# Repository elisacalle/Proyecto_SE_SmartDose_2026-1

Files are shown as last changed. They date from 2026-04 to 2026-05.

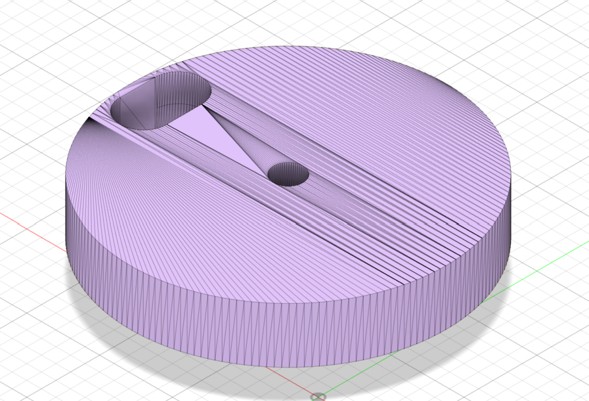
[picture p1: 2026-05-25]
Imágenes/Rotador.jpg

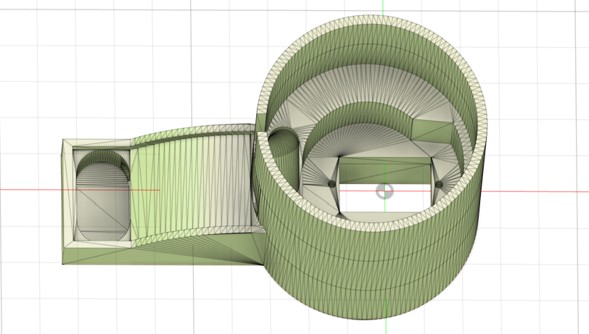
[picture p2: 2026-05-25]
Imágenes/base_sistema.jpg

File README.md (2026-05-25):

# SmartDose: Sistema Automatizado de Dispensación de Medicamentos Programados

## Introducción
#### Contexto del problema:
A medida que la población colombiana tiende al envejecimiento, y el aumento sostenido de enfermedades crónicas, tales como diabetes o hipertensión, ha generado un escenario en el que millones de personas dependen de instrucciones farmacológicas complejas y específicas para conservar su calidad de vida. Sin embargo, gestionar mentalmente qué se debe tomar y a qué hora, representa una carga cognitiva considerable, principalmente entre los adultos mayores que no tienen un cuidador constante. Dicho esto, el olvido de tomar los medicamentos no es un evento irrelevante, puede desencadenar crisis de salud, empeoramiento del cuadro clínico que deriva en hospitalizaciones de emergencia o el deterioro acelerado de las condiciones a tratar, todas consecuencias que, con la administración correcta de los fármacos, se pueden controlar.

#### Importancia y por qué vale la pena resolverlo:
La mala adherencia terapéutica no resulta en consecuencias únicamente para el paciente: representa una sobrecarga al ya presionado sistema de salud pública y a las familias que deben asumir el esfuerzo económico y de tiempo para acompañar a su ser querido y garantizar su bienestar. Si se logra automatizar la dispensación de medicamentos, se elimina el eslabón más débil de la cadena, la memoria humana y la capacidad de seguir indicaciones; más allá del beneficio directo que obtiene el paciente al seguir con su tratamiento como está estipulado, esta solución también les devuelve libertad a los pacientes y reduce la carga del entorno familiar. Resolver este problema con un sistema embebido de bajo costo convierte la solución en una replicable, accesible y sobre todo útil para la sociedad.

#### Área de aplicación:
SmartDose se encuentra justo en la frontera donde, los sistemas embebidos, la ingeniería aplicada a la salud y automatización y control se encuentran. No es un dispositivo médico en el sentido legal o regulatorio, es una solución de ingeniería orientada a un problema humano concreto, dándole visibilidad a las dificultades que día a día pueden enfrentar los enfermos crónicos para su tratamiento. Este proyecto aspira a demostrar como la electrónica, sensores de bajo costo y microcontroladores tienen la capacidad de construir herramientas que impacten realmente a la sociedad.

## Descripción del Problema

La adherencia terapéutica, entendida como el cumplimiento correcto de un tratamiento farmacológico en dosis, frecuencia y horario, representa uno de los desafíos más críticos en el cuidado de pacientes con enfermedades crónicas. Según la Organización Mundial de la Salud, cerca del 50% de los pacientes con enfermedades crónicas no toman sus medicamentos de la forma prescrita, lo que deriva en complicaciones clínicas evitables, hospitalizaciones innecesarias y un deterioro progresivo de la calidad de vida. Este problema se agudiza significativamente en adultos mayores, quienes con frecuencia deben gestionar múltiples medicamentos con horarios distintos, presentan dificultades cognitivas asociadas al envejecimiento y en muchos casos no cuentan con acompañamiento permanente de un cuidador.

La situación actual en hogares y entornos de cuidado domiciliario depende casi exclusivamente de la memoria del paciente o de recordatorios manuales por parte de los familiares o cuidadores. Los pastilleros convencionales, aunque organizan visualmente la medicación por días y tomas, no generan alertas, no verifican si la pastilla fue tomada efectivamente y no registran el historial de dispensaciones. Las alarmas de celular, si bien son una solución parcial, requieren que el paciente identifique correctamente cuál medicamento tomar, en qué dosis y en qué momento, lo que en pacientes con deterioro cognitivo representa una fuente frecuente de errores. 

Se identifica que lo que falta es un sistema autónomo, embebido y de bajo costo que gestione de forma automática los horarios de medicación, dispense físicamente el medicamento en el momento correcto, alerte al paciente de forma sonora para que no ignore la toma, detecte si el compartimiento está vacío antes de intentar dispensar y registre con trazabilidad temporal cada evento relevante del proceso. Un sistema así eliminaría la dependencia de la memoria del paciente, reduciría los errores de medicación y proporcionaría al cuidador o familiar un historial consultable del comportamiento del sistema.

Un caso aplicado puede ser el de la abuela de uno de nuestros integrantes, que debido a la diabetes y su avanzada edad debe tomar durante el día diferentes cantidades de medicamentos a horas muy exactas. Debido a su condición de vejez es propensa a que se le olvide tomarlos a las horas precisas y adecuadas, como aún vive sola, para su familia tiende a ser un poco complejo supervisar o consultar todo el historial de toma de las pastillas de forma adecuada, la invención de este sistema sería una alternativa o solución bastante factible para su condición y de esta forma podría sentirse mas independiente y a su familia le daría la tranquilidad de que cumple de forma precisa con la toma de sus medicamentos. 

## Alcance del Proyecto
#### ¿Qué incluye el proyecto?
-Programación de hasta 4 horarios de dispensación diarios configurables desde la GUI (Graphical User Interface).

-Dispensación automática de n dosis (pastilla) por evento programado.

-Detección de si la pastilla fue dispensada correctamente mediante sensor de presencia.

-Alerta sonora y visual (buzzer + led) si el usuario no recoge la pastilla después de un tiempo.

-Sistema de logging con timestamp, niveles INFO/WARN/ERROR y códigos estructurados. Se utiliza comunicación UART.

-Interfaz gráfica NX4832K035, pantalla táctil con comunicación UART serial.

-RTS DS3231 para manejo del tiempo, se comunica por vía I2C.

-Firmware estructurado, con manejo de errores y documentación.

#### Prototipo esperado
-Tarjeta universal ensamblada dentro de una carcasa impresa en 3D o construida en acrílico/madera MDF.

-Fuente de alimentación externa.

#### Límites técnicos
-Microcontrolador ESP32.

-Protocolos usados: I2C (RTC DS3231), UART (logging).

-El sistema no distingue el tipo de medicamento.

-No es un dispositivo medico certificado.

-No incluye conectividad WI-FI o bluetooth.

-No controla temperatura de almacenamiento.

## Objetivo General

Desarrollar un sistema embebido de bajo costo para la dispensación automática de medicamentos en horarios programados, con configuración mediante interfaz gráfica, generación de alertas al usuario, detección de condiciones de fallo y registro trazable de eventos con marca temporal.

## Objetivos Específicos

#### #1
Implementar la programación de hasta cuatro horarios diarios configurables desde la interfaz gráfica del sistema.

#### #2
Automatizar la dispensación física de la dosis programada en cada evento de medicación.

#### #3
Incorporar mecanismos de alerta sonora y visual, incluyendo notificación por no recolección.

#### #4
Registrar los eventos relevantes del sistema mediante un esquema de logging estructurado con marca temporal y niveles de severidad.

## Asignación de Roles
#### Technical Lead:
Elisa Calle Escobar

#### Firmware Engineer:
David Aristizábal

#### Hardware Integration Engineer:
Gabriel García 

#### Verification & Testing Engineer:
Santiago Soto

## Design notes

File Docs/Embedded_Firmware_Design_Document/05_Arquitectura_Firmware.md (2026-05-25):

# SmartDose — Arquitectura de Firmware

Sistema automático de dispensación de medicamentos basado en **ESP32** con **FreeRTOS**, desarrollado con ESP-IDF y PlatformIO.

---

## Tabla de contenidos

1. [Visión general](#1-visión-general)
2. [Hardware y pines](#2-hardware-y-pines)
3. [Estructura del firmware](#3-estructura-del-firmware)
4. [Tareas FreeRTOS](#4-tareas-freertos)
5. [Módulos de software](#5-módulos-de-software)
6. [Integración ESP32–Nextion](#6-integración-esp32nextion)
7. [Máquina de estados por tubo](#7-máquina-de-estados-por-tubo)
8. [Flujo de dispensación](#8-flujo-de-dispensación)
9. [Protocolo de comandos](#9-protocolo-de-comandos)
10. [Persistencia — NVS](#10-persistencia--nvs)
11. [Parámetros configurables](#11-parámetros-configurables)

---

## 1. Visión general



SmartDose controla hasta **4 tubos dispensadores** de forma independiente. La **Nextion** actúa exclusivamente como interfaz gráfica: recibe toques del usuario y muestra el estado del sistema. El **ESP32** centraliza toda la lógica: valida comandos, guarda horarios, ejecuta dispensaciones y actualiza la pantalla. La Nextion no controla motores ni sensores directamente.

---

## 2. Hardware y pines

| Componente | GPIO | Interfaz |
|---|---|---|
| Servo Tubo 1 | 14 | LEDC / PWM |
| Servo Tubo 2 | 27 | LEDC / PWM |
| Servo Tubo 3 | 16 | LEDC / PWM |
| Servo Tubo 4 | 17 | LEDC / PWM |
| IR Bandeja Tubo 1 | 36 | GPIO entrada |
| IR Bandeja Tubo 2 | 39 | GPIO entrada |
| IR Bandeja Tubo 3 | 25 | GPIO entrada |
| IR Bandeja Tubo 4 | 26 | GPIO entrada |
| Buzzer | 13 | GPIO salida |
| LED de alerta | 12 | GPIO salida |
| I2C SDA (DS3231) | 21 | I2C Master |
| I2C SCL (DS3231) | 22 | I2C Master |
| UART0 TX/RX | — | Consola / depuración (115200 bps) |
| UART1 TX → Nextion | 5 | UART1 (9600 bps) |
| UART1 RX ← Nextion | 4 | UART1 (9600 bps) |

| Periférico | Driver ESP-IDF | Uso |
|---|---|---|
| Servos x4 | `driver/ledc` | PWM 50 Hz, 14 bits |
| Sensores IR x4 | `driver/gpio` | Entrada digital con pull-up |
| Buzzer + LED | `driver/gpio` | Salida digital |
| DS3231 | `driver/i2c` | Lectura/escritura de hora |
| Consola | `driver/uart` UART0 | Comandos de depuración |
| Nextion HMI | `driver/uart` UART1 | Interfaz táctil |
| Persistencia | `nvs_flash` / `nvs` | Horarios y flag RTC |

---

## 3. Estructura del firmware

Todo el firmware reside en `main.c`, organizado en secciones funcionales:

```
main.c
│
├── Definiciones de pines y parámetros (#define)
├── Estructuras de datos (horario_t, info_tubo_t, estado_tubo_t)
├── Variables globales + mutex FreeRTOS + buffer de logs
│
├── [Módulo] Servo         — angulo_a_duty(), servo_set(), servo_dispensar()
├── [Módulo] Sensor IR     — sensor_leer() con debounce, bandeja_tiene_pastilla()
├── [Módulo] Alertas       — buzzer_set(), led_set(), actualizar_salidas_alarma()
├── [Módulo] RTC DS3231    — ds3231_leer(), ds3231_get_hora(), ds3231_set_hora()
├── [Módulo] Nextion HMI   — nextion_cmd(), nextion_set_txt(), nextion_set_val()
│                            nextion_actualizar_pantalla(), nextion_actualizar_logs()
│                            nextion_actualizar_campos_config(), nextion_actualizar_horarios_page0()
│                            nextion_limpiar_campos_config()
├── [Módulo] NVS           — nvs_guardar(), nvs_cargar(), nvs_borrar_horarios()
│                            rtc_ya_configurado(), marcar_rtc_configurado()
├── [Módulo] Log           — smartdose_log(), log_evento(), log_error_01()
├── [Módulo] Dispensación  — ciclo_dispensacion(), solicitar_dispensacion()
│                            dispensar_con_reintentos_y_confirmar_bandeja()
├── [Módulo] Comandos      — procesar_comando(), configurar_horario()
│                            ack_tubo(), borrar_todos_los_horarios()
│
└── Tareas FreeRTOS
    ├── tarea_scheduler
    ├── tarea_monitor
    ├── tarea_uart_monitor
    ├── tarea_nextion_rx
    ├── tarea_nextion_update
    └── tarea_dispensacion (dinámica por tubo)
```

### Estructuras de datos

```c
typedef enum { TUBO_OK, TUBO_DISPENSANDO, TUBO_FALLO } estado_tubo_t;

typedef struct {
    bool activo;
    int  hora, minuto, cantidad;  // cantidad: 1–10 pastillas
} horario_t;

typedef struct {
    estado_tubo_t estado;
    bool          pastilla_en_bandeja;
    bool          alerta_activa;
} info_tubo_t;
```

Todas las lecturas/escrituras sobre `g_horarios[]` y `g_info[]` están protegidas con un **mutex FreeRTOS** (`g_mutex`). Los últimos 5 eventos del sistema se mantienen en `g_logs[5][120]`.

---

## 4. Tareas FreeRTOS

| Tarea | Prioridad | Stack | Período | Función |
|---|---|---|---|---|
| `tarea_scheduler` | 6 | 4 KB | 1 s | Compara hora RTC con horarios; lanza dispensación automática |
| `tarea_nextion_rx` | 5 | 4 KB | Reactiva | Lee comandos enviados por la Nextion vía UART1 |
| `tarea_monitor` | 4 | 4 KB | 7 s | Verifica bandejas y actualiza alertas |
| `tarea_uart_monitor` | 3 | 4 KB | Reactiva | Lee comandos desde consola UART0 |
| `tarea_nextion_update` | 2 | 4 KB | 1.5 s | Refresca la pantalla Nextion periódicamente |
| `tarea_dispensacion` | 7 | 4 KB | Bajo demanda | Creada por tubo; se auto-elimina al terminar |

> `tarea_dispensacion` se crea con `xTaskCreate()` por horario o comando manual, y se elimina con `vTaskDelete(NULL)` al completar el ciclo.

---

## 5. Módulos de software

### Servo (LEDC PWM)
- **50 Hz**, resolución **14 bits**, pulso **600–2500 µs**.
- Apertura: **180°** → Cierre: **0°**, con `SERVO_MS_ACCION = 400 ms` entre posiciones.
- Conversión: `us = 600 + (2500-600) * angulo / 180` → `duty = (us * 16383) / 20000`

### Sensor IR de bandeja (FC-51)
- Anti-rebote por software: **3 muestras** con 10 ms de separación; mayoría decide.
- `SENSOR_ACTIVO_EN_LOW = 1` → LOW = objeto presente.

### RTC DS3231
- I²C a **400 kHz**, dirección `0x68`. Conversión BCD ↔ decimal implementada manualmente.
- Si no fue configurado previamente (flag en NVS), se inicializa a hora por defecto al arrancar.

### Alertas
- `actualizar_salidas_alarma()` enciende LED y buzzer si **cualquier** tubo tiene `alerta_activa = true` o `pastilla_en_bandeja = true`.

### Sistema de logs
- Formato: `HH:MM:SS | NIVEL [CODIGO] | T<n>/SYS | Mensaje`
- Buffer circular de 5 entradas en `g_logs[]`. El más reciente queda en `g_logs[0]`.
- Cada log se escribe por `printf`, se guarda en el buffer y se envía a la Nextion.

### NVS
- Namespace `"smartdose"`, claves: `"horarios"` (string) y `"rtc_set"` (uint8).
- `nvs_borrar_horarios()` escribe `"VACIO"` explícitamente para evitar datos corruptos tras reinicios inesperados.

---

## 6. Integración ESP32–Nextion

### Comunicación física

```
UART0 → Consola VSCode (115200 bps) — depuración y comandos manuales
UART1 → Nextion HMI  (9600 bps)    — interfaz táctil bidireccional

Nextion TX → GPIO4 (ESP32 RX)
Nextion RX → GPIO5 (ESP32 TX)
```

TX y RX deben estar cruzados. GND común entre todos los módulos.

### Protocolo de comunicación

**Nextion → ESP32:** cadenas ASCII terminadas en `\r\n` o `0xFF 0xFF 0xFF`.

Ejemplo de evento táctil en Nextion (botón Guardar T1):
```
prints "T1=",0
prints nT1H.val,0
prints ":",0
prints nT1M.val,0
prints ":",0
prints nT1C.val,0
printh 0D 0A
```

**ESP32 → Nextion:** comandos ASCII terminados siempre en `0xFF 0xFF 0xFF`.

```c
// Toda escritura pasa por nextion_write_raw(), que agrega 0xFF 0xFF 0xFF
nextion_set_txt("tHora", "14:23:08");   // → tHora.txt="14:23:08" + FF FF FF
nextion_set_val("jAlerta", 100);        // → jAlerta.val=100 + FF FF FF
nextion_cmd("page page2");              // → page page2 + FF FF FF
```

### Funciones de envío (ESP32 → Nextion)

| Función | Uso |
|---|---|
| `nextion_write_raw(s)` | Envía string crudo + terminador `0xFF 0xFF 0xFF` |
| `nextion_cmd(fmt, ...)` | Construye comando con formato y llama a `write_raw` |
| `nextion_set_txt(obj, txt)` | Actualiza texto de un componente. Filtra comillas dobles |
| `nextion_set_val(obj, val)` | Actualiza valor numérico o barra de progreso |

### Funciones de sincronización de pantalla

| Función | Qué actualiza |
|---|---|
| `nextion_actualizar_pantalla()` | Hora RTC, horarios `page0`, `tMsg`, `jAlerta`, logs |
| `nextion_actualizar_horarios_page0()` | `tT1Hor`…`tT4Hor` con horario activo o `"Sin horario"` |
| `nextion_actualizar_campos_config()` | `nT1H`, `nT1M`, `nT1C`…`nT4C` con valores reales de RAM |
| `nextion_limpiar_campos_config()` | Resetea campos numéricos a 0/0/1 |
| `nextion_actualizar_logs()` | `tLog1`…`tLog5` con el buffer circular `g_logs[]` |

> **Fuente de verdad:** el ESP32, no la Nextion. Los valores de la pantalla solo son válidos después de que el ESP32 los recibe, valida y guarda en memoria.

### Páginas de la Nextion

| Página | Cuándo se muestra | Contenido principal |
|---|---|---|
| `page0` | Funcionamiento normal | Hora, horarios activos, mensaje general |
| `page1` | Configuración de horarios | Campos numéricos hora/minuto/cantidad por tubo |
| `page2` | Dosis en bandeja | Alerta de retiro de pastilla |
| `page3` | Error de dispensación | Mensaje ERROR 01 y descripción de fallo |
| `page4` | Historial | Últimos 5 eventos (`tLog1`…`tLog5`) |

### Recepción de comandos (tarea_nextion_rx)



`procesar_comando()` es compartida entre UART0 y UART1. El prefijo `nxt:` enviado desde Nextion se elimina automáticamente antes de interpretar el comando.

---

## 7. Máquina de estados por tubo



---

## 8. Flujo de dispensación

```
solicitar_dispensacion(idx)
        │
        ├── Tubo en TUBO_DISPENSANDO → rechazar
        └── xTaskCreate(tarea_dispensacion)
                    │
                    ▼
            ciclo_dispensacion(idx)
                    │
                    ├── [1] Estado → TUBO_DISPENSANDO
                    │
                    ├── [2] Hasta 4 reintentos:
                    │       servo: 180° → 400ms → 0° → 400ms
                    │       esperar sensor bandeja (máx 3 s)
                    │       ├── Detectado → Éxito
                    │       └── Timeout → WARN log → siguiente intento
                    │
                    ├── [3a] ÉXITO → TUBO_OK, alerta ON, page2
                    │       Esperar retiro (confirmación doble 300 ms)
                    │       └── Bandeja vacía → alarma OFF, page0, log INFO
                    │
                    └── [3b] FALLO → TUBO_FALLO, alerta ON, page3, log ERROR 01
                              15 s → alarma OFF, TUBO_FALLO persiste hasta ACK
```

---

## 9. Protocolo de comandos

Aceptados desde **UART0** (consola) y **UART1** (Nextion). No distinguen mayúsculas/minúsculas.

| Comando | Descripción | Ejemplo |
|---|---|---|
| `T<n>=HH:MM:C` | Configurar horario de un tubo | `T1=08:30:1` |
| `CFG,tubo,hora,min,cantidad` | Formato alternativo | `CFG,1,8,30,1` |
| `DISP<n>` | Dispensación manual | `DISP2` |
| `ACK<n>` | Confirmar y limpiar alerta | `ACK1` |
| `SETTIME=HH:MM:SS` | Sincronizar RTC | `SETTIME=09:15:00` |
| `STATUS` / `REFRESH` | Estado en consola + refresco Nextion | `STATUS` |
| `CLEAR` / `BORRAR` | Borrar todos los horarios | `CLEAR` |

**Validaciones:** Tubo 1–4 · Hora 0–23 · Minuto 0–59 · Cantidad 1–10

---

## 10. Persistencia — NVS

```
NVS namespace: "smartdose"
│
├── "horarios" → "T1=08:30:1;T3=20:00:2"   (string, máx 256 bytes)
└── "rtc_set"  → 0x01                        (uint8, flag de configuración)
```

- Los horarios se serializan como texto separado por `;`. Si no hay horarios, se almacena `"VACIO"`.
- Al arrancar, `nvs_cargar()` parsea el string y reconstruye `g_horarios[]`.
- `nvs_borrar_horarios()` escribe `"VACIO"` explícitamente para evitar datos residuales tras reinicios inesperados.

---

## 11. Parámetros configurables

| Parámetro | Valor | Descripción |
|---|---|---|
| `MAX_TUBOS` | 4 | Número de tubos dispensadores |
| `SERVO_FREQ_HZ` | 50 | Frecuencia PWM |
| `SERVO_MIN_US` | 600 | Pulso mínimo servo (µs) |
| `SERVO_MAX_US` | 2500 | Pulso máximo servo (µs) |
| `SERVO_ANGULO_ABIERTO` | 180° | Ángulo de apertura |
| `SERVO_ANGULO_CERRADO` | 0° | Ángulo de cierre |
| `SERVO_MS_ACCION` | 400 ms | Tiempo entre posiciones del servo |
| `TIMEOUT_CAIDA_MS` | 3000 ms | Espera máxima para detectar pastilla en bandeja |
| `TIMEOUT_RECOGIDA_MS` | 60000 ms | Espera máxima antes de re-alertar pastilla no retirada |
| `ERROR_ALARMA_MS` | 15000 ms | Duración de alarma en fallo de dispensación |
| `MAX_REINTENTOS_CAIDA` | 4 | Intentos antes de declarar ERROR 01 |
| `DEBOUNCE_COUNT` | 3 | Muestras para anti-rebote del sensor IR |
| `TICK_SCHEDULER_MS` | 1000 ms | Período del scheduler |
| `TICK_MONITOR_MS` | 7000 ms | Período de monitoreo de bandejas |
| `TICK_NEXTION_MS` | 1500 ms | Período de refresco de pantalla |
| `MAX_LOGS` | 5 | Entradas del buffer circular de logs |
| `NEXTION_BAUD` | 9600 | Baudrate UART1 Nextion |
| `SENSOR_ACTIVO_EN_LOW` | 1 | Lógica del sensor IR (1 = LOW activo) |

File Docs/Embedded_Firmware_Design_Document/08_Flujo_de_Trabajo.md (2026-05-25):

# SmartDose — Estructura del Repositorio y Flujo de Trabajo

---

## Tabla de contenidos

1. [Estructura de directorios](#1-estructura-de-directorios)
2. [Descripción de carpetas](#2-descripción-de-carpetas)
   - [Raíz del repositorio](#raíz-del-repositorio)
   - [Docs/](#docs)
   - [Firmware/](#firmware)
   - [Hardware/](#hardware)
   - [Images/](#images)
3. [Flujo de trabajo del repositorio](#3-flujo-de-trabajo-del-repositorio)

---

## 1. Estructura de directorios

```
SmartDose/
│
├── Docs/
│   └── Embedded_firmware_design_document/
│       ├── Introduccion
│       ├── Objetivos_proyecto
│       ├── Hardware_Architecture
│       ├── Diagrama_de_bloques
│       ├── Arquitectura_firmware
│       ├── Diagrama_de_estados
│       ├── Estrategia_de_manejo_de_errores
│       ├── Flujo_de_trabajo
│       ├── Estrategia_de_logging
│       ├── Gestion_de_comunicaciones
│       ├── Matriz_de_trazabilidad_de_requerimientos
│       ├── Casos_de_prueba
│       └── Decisiones_de_diseno_justificadas
│
├── Firmware/
│   ├── include/
│   ├── lib/
│   │   └── src/
│   │       └── main/
│   │           └── main.c
│   ├── test/
│   ├── .gitignore
│   ├── CMakeLists.txt
│   ├── platformio.ini
│   └── sdkconfig.az-delivery-devkit-v4
│
├── Hardware/
│   ├── Interfaz_grafica/
│   ├── Dispensador.step
│   ├── Esquematico_SmartDose.md
│   └── Prototipo_funcional/
│
├── Imágenes/
│   └── (diseño físico del sistema)
│
└── README.md
```

---

## 2. Descripción de carpetas

### Raíz del repositorio

| Elemento | Descripción |
|---|---|
| `README.md` | Punto de entrada del repositorio. Contiene la descripción general del proyecto, problema que resuelve, objetivos, tecnologías usadas, instrucciones de instalación y referencias a las demás secciones. |
| `Docs/` | Documentación técnica completa del sistema. |
| `Firmware/` | Todo el código fuente del ESP32 y archivos de configuración del entorno de desarrollo. |
| `Hardware/` | Archivos de diseño físico, esquemático e interfaz gráfica. |
| `Imágenes/` | Registro fotográfico del prototipo físico construido. |

---

### Docs/

Contiene el **Embedded Firmware Design Document**, documento técnico que cubre la totalidad del diseño del sistema desde sus objetivos hasta sus casos de prueba.

| Sección | Contenido |
|---|---|
| `Introduccion` | Contexto del proyecto, problema que resuelve y alcance del sistema. |
| `Objetivos_proyecto` | Objetivos generales y específicos del sistema SmartDose. |
| `Hardware_Architecture` | Descripción de componentes físicos, pines, interfaces y periféricos del ESP32. |
| `Diagrama_de_bloques` | Representación visual de la interacción entre subsistemas (ESP32, servos, sensores, RTC, Nextion, NVS). |
| `Arquitectura_firmware` | Estructura del código, módulos de software, tareas FreeRTOS y estructuras de datos. |
| `Diagrama_de_estados` | Máquina de estados por tubo: `TUBO_OK`, `TUBO_DISPENSANDO`, `TUBO_FALLO` y sus transiciones. |
| `Estrategia_de_manejo_de_errores` | Catálogo de errores detectados, flujo de manejo automático, alarmas y acciones del operador. |
| `Flujo_de_trabajo` | Estructura del repositorio y flujo de desarrollo del proyecto. |
| `Estrategia_de_logging` | Formato del sistema de logs en memoria, niveles de severidad y visualización en Nextion. |
| `Gestion_de_comunicaciones` | Protocolo UART0 (consola), UART1 (Nextion) e I2C (DS3231): tramas, baudrates y parsing. |
| `Matriz_de_trazabilidad_de_requerimientos` | Relación entre requerimientos del sistema y su implementación en el firmware. |
| `Casos_de_prueba` | Pruebas funcionales definidas para validar el comportamiento del sistema. |
| `Decisiones_de_diseno_justificadas` | Registro de decisiones técnicas tomadas durante el desarrollo y su justificación. |

---

### Firmware/

Contiene el proyecto completo de firmware desarrollado con **ESP-IDF** y gestionado con **PlatformIO**.

| Elemento | Descripción |
|---|---|
| `include/` | Archivos de cabecera (`.h`) del proyecto. |
| `lib/src/main/main.c` | Archivo principal del firmware. Contiene la totalidad de la lógica del sistema: inicialización de periféricos, tareas FreeRTOS, módulos de servo, sensor IR, RTC, Nextion, NVS, logs y manejo de comandos. |
| `test/` | Carpeta reservada para pruebas unitarias del firmware. |
| `.gitignore` | Define los archivos y carpetas excluidos del control de versiones (`.pio/`, `build/`, archivos temporales). |
| `CMakeLists.txt` | Archivo de configuración del sistema de build de ESP-IDF. Define los componentes y fuentes del proyecto. |
| `platformio.ini` | Archivo de configuración de PlatformIO. Define la plataforma (`espressif32`), el board (`az-delivery-devkit-v4`), el framework (`espidf`) y opciones de compilación. |
| `sdkconfig.az-delivery-devkit-v4` | Configuración del SDK de ESP-IDF específica para el módulo AZ-Delivery DevKit V4 (ESP32). Contiene parámetros de particiones, frecuencia de CPU, flash y más. |

---

### Hardware/

Contiene los archivos de diseño físico y electrónico del sistema.

| Elemento | Descripción |
|---|---|
| `Interfaz_grafica/` | Archivos del proyecto Nextion HMI (`.HMI`): páginas, componentes, eventos touch y lógica de la pantalla táctil. |
| `Dispensador.step` | Modelo 3D del mecanismo dispensador en formato STEP, compatible con Fusion 360, SolidWorks y otros CAD. |
| `Esquematico_SmartDose.md` | Esquemático del circuito electrónico: conexiones entre ESP32, servos, sensores IR, DS3231, buzzer, LED y Nextion. |
| `Prototipo_funcional/` | Fotografías y/o archivos de referencia del prototipo físico ensamblado y funcionando. |

---

### Imágenes/

| Elemento | Descripción |
|---|---|
| Fotografías | Registro visual del diseño físico del sistema SmartDose ensamblado. Usadas como referencia en el `README.md` y la documentación técnica. |

---

## 3. Flujo de trabajo del repositorio



### Flujo detallado

**1. Configuración del entorno**

- Instalar [PlatformIO](https://platformio.org/) como extensión de VS Code.
- Clonar el repositorio y abrir la carpeta `Firmware/` como proyecto PlatformIO.
- El archivo `platformio.ini` configura automáticamente el framework ESP-IDF y el board correcto (`az-delivery-devkit-v4`).

**2. Desarrollo de firmware**

- Todo el código del sistema reside en `Firmware/lib/src/main/main.c`.
- Los parámetros de comportamiento (timeouts, pines, ángulos, períodos) se modifican únicamente en la sección de `#define` al inicio del archivo.
- Compilar con el comando de PlatformIO: `Build` o `pio run`.

**3. Programación del dispositivo**

- Conectar el ESP32 por USB.
- Usar `Upload` en PlatformIO (`pio run --target upload`) para flashear el firmware.
- Verificar el arranque correcto con el monitor serial a **115200 bps** (`pio device monitor`).

**4. Pruebas**

- Las pruebas funcionales se ejecutan enviando comandos por el monitor serial (`DISP1`, `STATUS`, `CFG,1,8,30,1`, etc.).
- Los casos de prueba definidos están documentados en `Docs/Embedded_firmware_design_document/Casos_de_prueba`.

**5. Control de versiones**

- Los archivos de build (`.pio/`, `build/`) están excluidos por `.gitignore`.
- Cada cambio funcional verificado se consolida en un commit descriptivo antes de subir al repositorio.
- La documentación en `Docs/` se actualiza en paralelo al firmware cuando hay cambios de comportamiento, interfaces o parámetros.

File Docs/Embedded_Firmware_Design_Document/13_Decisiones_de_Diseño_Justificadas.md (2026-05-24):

# Decisiones de diseño justificadas - SmartDose

## 1. Descripción general del proyecto

SmartDose es un prototipo de dispensador automático de pastillas basado en un ESP32, una pantalla Nextion NX4832K035, un módulo de reloj DS3231, servomotores, sensor infrarrojo de bandeja, buzzer y LED de alerta.

El sistema permite configurar horarios de dispensación para cuatro tubos independientes. Para cada tubo se define una hora, un minuto y una cantidad de activaciones del mecanismo. Cuando llega la hora programada, el ESP32 acciona el servomotor correspondiente, verifica si la dosis llegó a la bandeja y muestra el resultado en la interfaz gráfica.

## 2. Arquitectura general

La arquitectura se organiza en cuatro bloques:

| Bloque | Componente | Función |
|---|---|---|
| Control central | ESP32 | Ejecuta la lógica, controla servos, lee sensores y actualiza la interfaz |
| Interfaz de usuario | Nextion NX4832K035 | Permite configurar horarios, visualizar alertas y consultar logs |
| Tiempo real | RTC DS3231 | Mantiene la hora real del sistema |
| Dispensación | Servomotores + sensor IR de bandeja | Ejecutan y validan la dispensación |

Esta distribución permite que la pantalla no controle directamente el proceso crítico, la Nextion recibe y envía información, pero el ESP32 decide cuándo dispensar, cuándo activar alarmas y cómo registrar los eventos.

## 3. Elección del ESP32

Se seleccionó el ESP32 porque ofrece suficientes pines GPIO, comunicación UART, comunicación I2C y soporte de multitarea mediante FreeRTOS.

Esta decisión permite:

- Controlar cuatro servomotores de forma independiente.
- Leer sensores digitales de bandeja.
- Comunicarse con la Nextion mediante UART.
- Comunicarse con el DS3231 mediante I2C.
- Guardar horarios en memoria no volátil.
- Ejecutar tareas separadas para dispensación, monitoreo, comunicación y actualización de pantalla.

La multitarea es útil porque el sistema debe seguir recibiendo comandos y actualizando la interfaz mientras una dispensación está en curso.

## 4. Elección de la pantalla Nextion

Se incorporó una pantalla Nextion NX4832K035 para mejorar la interacción con el usuario. Esta pantalla permite diseñar una interfaz táctil con páginas, botones, textos y mensajes de alerta.

La Nextion permite:

- Mostrar la hora actual del RTC.
- Configurar horarios y cantidades de dispensación.
- Mostrar alertas de dosis lista.
- Mostrar errores de dispensación.
- Visualizar logs del sistema.

La pantalla se comporta como una HMI. El ESP32 conserva el control lógico del proceso y la Nextion solo actúa como interfaz de entrada y salida.

## 5. Comunicación ESP32–Nextion

La comunicación entre ESP32 y Nextion se realiza mediante UART1 a 9600 baudios.

Configuración usada:

```c
#define UART_NUM_NEXTION UART_NUM_1
#define NEXTION_TX_GPIO  5   // ESP32 TX -> RX Nextion
#define NEXTION_RX_GPIO  4   // ESP32 RX <- TX Nextion
#define NEXTION_BAUD     9600
```

Conexión física:

| Nextion | ESP32 |
|---|---|
| TX | GPIO4 |
| RX | GPIO5 |
| 5V | 5V |
| GND | GND común |

## 6. Uso del RTC DS3231

El sistema usa un RTC DS3231 para mantener una hora confiable. Esto es necesario porque SmartDose depende directamente de horarios programados.

La pantalla Nextion no asigna la hora del sistema. La hora se configura desde el ESP32 y se conserva en el DS3231. La Nextion únicamente muestra la hora que el ESP32 lee del RTC.

Esta decisión evita inconsistencias y mantiene una única fuente de verdad para el tiempo del sistema.

## 7. Retiro del sensor superior de almacenamiento

Inicialmente se planteó usar dos sensores por tubo:

1. Sensor superior para detectar si había pastillas almacenadas.
2. Sensor inferior para detectar si una pastilla llegó a la bandeja.

Durante el desarrollo se decidió retirar el sensor superior porque su detección lineal no era adecuada para inferir almacenamiento. Podía generar falsos estados dependiendo de la posición de las pastillas dentro del tubo.
Los posibles problemas del sensor superior eran indicar vacío aunque aún hubiera pastillas, indicar presencia aunque el compartimiento estuviera casi vacío, depender demasiado de la geometría interna del tubo, fallar si ninguna pastilla interrumpía exactamente el haz del sensor.
Por esto, desde la parte de Firmware se decidió que se intentara la dispensación en el horario programado con 4 intentos antes de marcar un error, este error puede estar relacionado a falta de suficientes pastillas o ubicación de las mismas.

Por eso se decidió validar la funcionalidad con el sensor de bandeja, que confirma el evento más importante: si la dosis llegó realmente al punto de retiro.

## 8. Uso del sensor de bandeja

El sistema final usa únicamente el sensor IR inferior ubicado en la bandeja de dispensación.

Este sensor tiene dos funciones:
1. Confirmar si una dosis fue dispensada.
2. Detectar cuándo el usuario retiró la dosis.

La lógica queda así:

```text
Llega la hora programada
→ Se activa el servomotor
→ El sistema espera detección en bandeja
→ Si hay detección, se muestra dosis lista
→ Si no hay detección, se reintenta la dispensación (4 intentos)
```

Esta solución reduce complejidad de hardware y permite validar el resultado real de la dispensación.

## 9. Reintentos de dispensación

Se implementó una lógica de reintentos. Si después de activar el servomotor no se detecta pastilla en la bandeja durante una ventana de 3 segundos, el sistema vuelve a accionar el motor.

El número máximo de intentos es:

```c
#define MAX_REINTENTOS_CAIDA 4
```

Esta decisión permite manejar situaciones como fricción, retrasos mecánicos o una pastilla parcialmente trabada. Si después de cuatro intentos no hay detección, el sistema declara un error.

## 10. Error 01

El sistema define un error crítico llamado Error 01.

Este error ocurre cuando, después de cuatro intentos de dispensación, el sensor de bandeja no detecta ninguna dosis.

El error se formula como un error general porque con un solo sensor no es posible saber con certeza si la causa fue ausencia de pastillas, atasco o falla del motor.

Causas posibles:

- Tubo vacío.
- Atasco mecánico.
- Falla del servomotor.
- Pastilla bloqueada.
- Problema en el mecanismo de salida.

## 11. Manejo de alertas

El sistema usa un LED Rojo y un buzzer.

### Dosis dispensada correctamente

Cuando el sensor de bandeja detecta una pastilla:

- Se muestra la página de dosis lista.
- Se enciende el LED.
- Se activa el buzzer.
- Ambos permanecen activos mientras la pastilla siga en la bandeja.

Cuando la persona retira la pastilla:

- El sensor deja de detectar.
- Se apagan LED y buzzer.
- La pantalla vuelve a la página principal.
- Se registra el evento en logs.

### Error de dispensación

Cuando ocurre el Error 01:

- Se muestra la página de error.
- Se encienden LED y buzzer.
- Se registra el error en logs.
- La alarma se mantiene durante 15 segundos y luego se apaga.

Se eligió limitar la alarma de error para evitar que el buzzer quede activo indefinidamente.

## 12. Interfaz gráfica

La interfaz Nextion se organiza en páginas.

### page0 — Pantalla principal

Muestra:
- Hora actual.
- Tubos.
- Horario programado de cada tubo.
- Mensaje general.
- Acceso a configuración, limpieza y logs.

### page1 — Configuración

Permite configurar:
- Hora.
- Minuto.
- Cantidad de dispensaciones.

Cada botón envía comandos como:

```text
T1=HH:MM:C
```

### page2 — Dosis lista

Se muestra cuando una dosis llega correctamente a la bandeja.

### page3 — Error de dispensación

Se muestra cuando ocurre Error 01.

### page4 — Logs

Muestra los últimos eventos del sistema.

## 13. Sistema de logs

El sistema registra eventos con niveles de severidad.

| Nivel | Uso |
|---|---|
| INFO | Eventos normales |
| WARN | Advertencias que requieren atención |
| ERROR | Fallas críticas |

Ejemplo de registros:

```text
15:42:01 | INFO | T1 | Horario guardado T1 15:45 x1
15:45:00 | INFO | T1 | Iniciando dispensación
15:45:03 | WARN | T1 | Dosis en bandeja, esperando retiro
15:45:12 | INFO | T1 | Pastilla retirada
15:50:08 | ERROR 01 | T2 | Falla general de dispensación
```

La pantalla muestra los últimos cinco logs, con el evento más reciente en la parte superior.

## 14. Seguridad y validación

El prototipo no debe probarse con medicamentos reales. Para pruebas se recomienda usar elementos simulados, como Tic Tac, dulces pequeños o piezas impresas.

El sistema valida funcionalidad, pero no corresponde a un dispositivo médico certificado. La validación debe centrarse en:

- Comunicación con pantalla.
- Configuración de horarios.
- Activación de servomotores.
- Detección de bandeja.
- Manejo de error.
- Registro de logs.

## 15. Conclusión

SmartDose integra control embebido, interfaz gráfica, temporización en tiempo real y validación por sensor. Las decisiones de diseño tomadas permiten mantener un prototipo funcional, modular y justificable.

La decisión más importante fue retirar el sensor superior y validar la dispensación con el sensor de bandeja, ya que esto prioriza el evento real de interés: que la dosis llegue al usuario. La integración con Nextion mejora la usabilidad al permitir configurar horarios, visualizar alertas y consultar logs sin depender de la terminal de desarrollo.

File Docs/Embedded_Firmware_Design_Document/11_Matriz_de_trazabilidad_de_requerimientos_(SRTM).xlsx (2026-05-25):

ID del requisito | Requisito | ID del caso de prueba | Tipo de prueba | Artefactos
RF-01 | Programar hasta cuatro horarios diarios desde la GUI | TC-001 | Integración / Sistema | Cámara, Logs guardados
RF-02 | Dispensar automáticamente en el horario programado | TC-002 | Integración | Cronómetro, Monitor serial (UART), Cámara, Logs guardados
RF-03 | Detectar si la pastilla fue dispensada correctamente | TC-003 | Integración / Fallo | Monitor serial (UART), Cámara, Logs guardados
RF-04 | Alerta si el usuario no recoge la pastilla | TC-004 | Sistema / Fallo | Monitor serial (UART), Cámara, LED, Buzzer
RF-05 | Detectar compartimento vacío antes de dispensar | TC-005 | Integración / Fallo | Monitor serial (UART), Cámara, Logs guardados
RF-06 | Alertar cuando el compartimento esté vacío | TC-006 | Sistema / Fallo | Monitor serial (UART), Cámara, Logs guardados
RF-07 | Registrar eventos con marca temporal | TC-007 | Integración | Monitor serial (UART), Logs guardados, RTC DS3221
RF-08 | Clasificar el log con niveles de severidad | TC-008 | Integración | Monitor serial (UART), Logs guardados
RF-09 | Mostrar hora, horarios configurados y estado en pantalla | TC-009 | Sistema | Cámara, Nextion
RF-10 | Modificar o eliminar horarios desde la GUI | TC-010 | Sistema | Cámara , Logs guardados, Nextion
RNF-01 | Respuesta a entrada táctil en menos de 500 ms | TC-011 | Sistema / Unitaria | Cronómetro, Cámara
RNF-02 | Precisión temporal máxima de ±1 minuto | TC-012 | Sistema | Cronómetro, Monitor serial (UART), Logs guardados
RNF-03 | Firmware modular con manejo de errores y documentación | TC-013 | Unitaria / Integración | Monitor serial (UART), Logs guardados
RNF-04 | Operación continua sin reinicio manual | TC-014 | Sistema / Fallo | Monitor serial (UART), Cámara, Logs guardados

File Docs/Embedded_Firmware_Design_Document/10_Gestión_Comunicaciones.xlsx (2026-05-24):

TABLA DE PROTOCOLOS DE COMUNICACIÓN
Protocolo | Interfaz / Uso | Dispositivo | Configuración | Justificación Técnica
UART | HMI / Display | Pantalla Nextion NX4832K035 | 9600 baud, 8N1 (1 start bit, 8 datos, sin paridad, 1 stop bit) | Comunicación simple y robusta ideal para interfaces HMI serie. La Nextion utiliza protocolo UART nativo; 9600 baud es suficiente para transferir comandos de actualización de pantalla sin sobrecarga.
UART0 | Depuración / Consola | Monitor serial (PC) | 115200 baud, 8N1 | Alta velocidad para logging en tiempo real durante desarrollo y pruebas. UART0 es el puerto predeterminado de depuración del ESP-IDF y no consume recursos de periféricos adicionales.
I2C | Sincronización temporal | RTC DS3231 | Modo Fast (400 kHz) Dirección esclavo: 0x68 | El bus I2C reduce el número de pines a solo 2 líneas (SDA/SCL) y permite conectar múltiples periféricos en el mismo bus. El DS3231 integra oscilador TCXO compensado en temperatura, ofreciendo alta precisión (±2 ppm) esencial para la programación de horarios de dispensación.
PWM | Actuación mecánica | Servomotores SG90 (×4) | Frecuencia: 50 Hz Ciclo útil: 5–10 % (0°–180°) | El requerimiento estándar de los servos RC exige señal PWM a 50 Hz. El ancho de pulso (1–2 ms) controla la posición angular con precisión suficiente para el mecanismo de dispensación. El ESP32 genera PWM por hardware mediante el módulo LEDC sin ocupar la CPU.

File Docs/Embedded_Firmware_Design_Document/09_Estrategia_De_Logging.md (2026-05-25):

# Estrategia de Logging

## 1. Descripción General

El sistema SmartDose implementa una estrategia de logging estructurado con el objetivo de permitir trazabilidad y monitoreo en tiempo real del comportamiento del sistema.

El sistema de logs registra eventos relevantes durante la operación, incluyendo:

- Inicio de dispensación
- Reintentos de caída de pastilla
- Fallos de dispensación
- Retiro de pastilla
- Configuración del sistema

El logging está diseñado para integrarse con el monitor serial, la interfaz HMI (Nextion) y los sistemas de alerta (LED y buzzer).

---

## 2. Niveles de Logging

El sistema define tres niveles de severidad:

| Nivel | Descripción |
|---|---|
| `INFO`  | Eventos normales del sistema |
| `WARN`  | Situaciones especiales no críticas |
| `ERROR` | Fallos críticos del sistema |

---

## 3. Formato de los Logs

Todos los eventos siguen un formato estructurado:

```
HH:MM:SS | NIVEL [CODIGO] | TUBO | MENSAJE
```

### Ejemplos reales del sistema

```
08:30:12 | ERROR 01 | T1 | Falla de dispensacion
08:30:05 | WARN     | T1 | No se detecto pastilla. Reintento 2/4
08:29:59 | INFO     | T1 | Iniciando dispensacion
```

---

## 4. Implementación en Firmware

El sistema de logging se implementa mediante la función:

```c
smartdose_log(int tubo, const char *nivel, const char *codigo, const char *msg);
```

Esta función:

1. Obtiene la hora desde el RTC (DS3231)
2. Construye el mensaje formateado
3. Lo imprime por UART0
4. Lo almacena en el buffer circular en memoria
5. Lo envía a la pantalla Nextion

---

## 5. Almacenamiento de Logs

Los logs se almacenan en un buffer circular en memoria RAM:

```c
#define MAX_LOGS 5
static char g_logs[MAX_LOGS][LOG_LEN];
```

Características:

- Se almacenan los **últimos 5 eventos**
- Los logs más antiguos se sobrescriben 
- Se prioriza eficiencia en memoria, acorde a las limitaciones del sistema embebido

---

## 6. Canales de Salida

### 6.1 Monitor Serial (UART0)

Los logs se imprimen usando:

```c
printf("%s\n", linea);
```

Uso principal: pruebas y validación del sistema.

### 6.2 Interfaz HMI (Nextion)

Los logs se muestran en pantalla mediante:

```c
nextion_actualizar_logs();
```

Distribución en pantalla:

| Componente | Función |
|---|---|
| `tLog1` | Log más reciente |
| `tLog5` | Log más antiguo  |

### 6.3 Alertas físicas (LED + Buzzer)

Los eventos críticos activan señales físicas (LED encendido, buzzer activo), controladas mediante:

```c
actualizar_salidas_alarma();
```

---

## 7. Eventos Registrados

### 7.1 Eventos INFO

| Evento | Descripción |
|---|---|
| Inicio de dispensación | Se inicia un ciclo de dispensa |
| Horario guardado | Configuración exitosa en NVS |
| Pastilla retirada | Fin del ciclo de dispensación  |

### 7.2 Eventos WARN

| Evento | Descripción |
|---|---|
| Reintento de dispensación | No se detectó caída de pastilla |
| Pastilla no recogida | Timeout de espera al usuario |

### 7.3 Eventos ERROR

| Código | Descripción |
|---|---|
| `ERROR 01` | Falla de dispensación tras 4 intentos fallidos |

Implementación:

```c
static void log_error_01(int tubo)
{
    smartdose_log(tubo, "ERROR", "01",
        "Falla de dispensacion: no se detecto dosis; "
        "posible atasco, tubo vacio o falla del motor");
}
```

---

## 8. Integración con el Sistema

El logging está directamente conectado con la lógica de dispensación. Flujo típico de un ciclo:

```
Inicio de ciclo     →  INFO   (Iniciando dispensacion)
Reintento N/4       →  WARN   (No se detecto pastilla)
Fallo definitivo    →  ERROR  (ERROR 01) + activación de alarma
Espera de retiro    →  WARN   (si se supera TIMEOUT_RECOGIDA_MS)
Pastilla retirada   →  INFO   (Pastilla retirada)
```

---

## 9. Retroalimentación en Tiempo Real

Cada log también actualiza el mensaje principal de la pantalla Nextion:

```c
nextion_set_txt("tMsg", resumen);
```

Esto permite que el usuario tenga visibilidad inmediata del estado del dispositivo sin necesidad de un PC conectado.

---

## 10. Decisiones de Diseño

### Buffer de 5 logs

Se eligió este tamaño por:

- Limitaciones de memoria RAM del ESP32 en contexto multitarea
- Suficiente para diagnóstico inmediato de un ciclo completo
- Compatible con el espacio disponible en la interfaz Nextion

### Uso de niveles (INFO / WARN / ERROR)

Permite:

- Clasificación clara de eventos por severidad
- Escalabilidad futura (posible filtrado por nivel)
- Mejor experiencia de depuración durante desarrollo

### Integración con HMI

Permite:

- Monitoreo del sistema sin necesidad de PC
- Diagnóstico visual inmediato para el usuario final

### Uso de RTC para timestamps

Garantiza:

- Trazabilidad real de eventos referenciada al tiempo absoluto
- Independencia del uptime del sistema ante reinicios

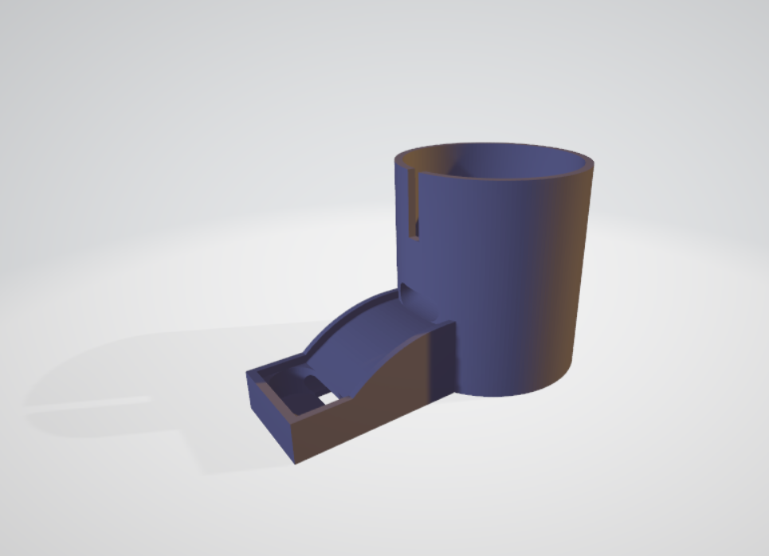
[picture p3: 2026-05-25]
Imágenes/Vista general.png

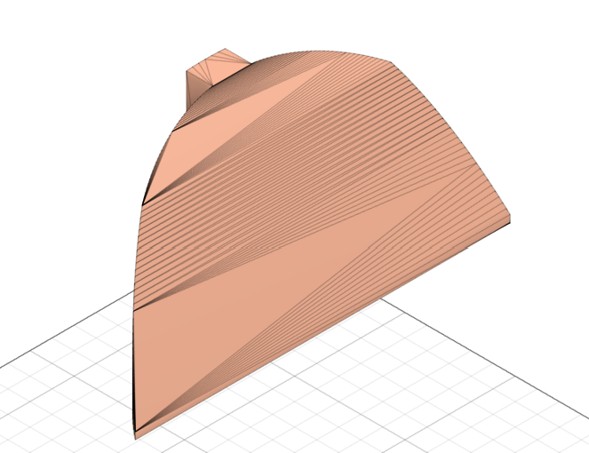
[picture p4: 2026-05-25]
Imágenes/Bloqueo.jpg

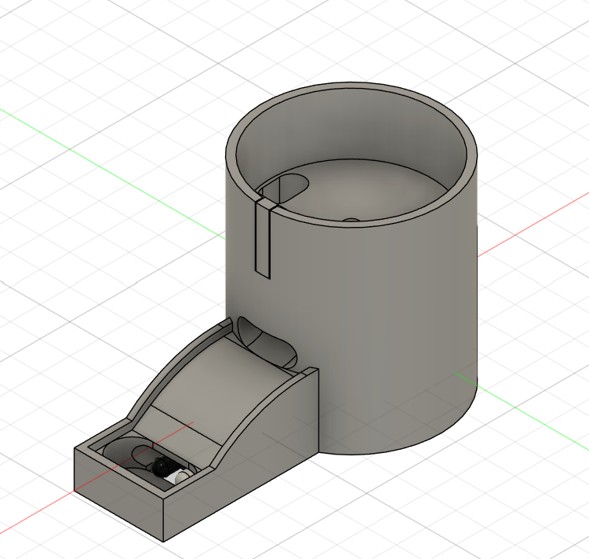
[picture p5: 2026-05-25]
Imágenes/Sistema_completo.jpg

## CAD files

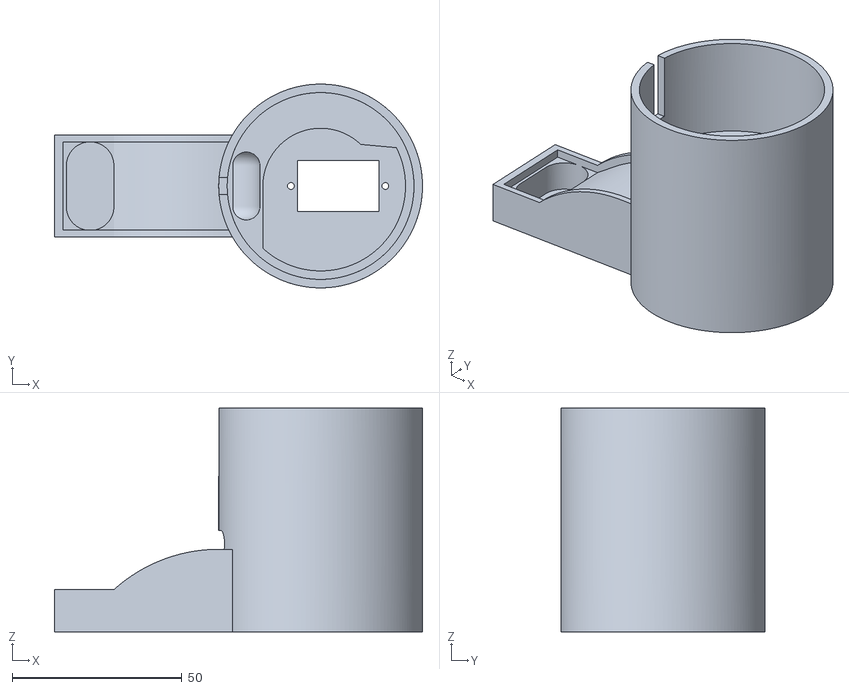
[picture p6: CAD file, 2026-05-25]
Hardware/Archivos STL/base.stl
108.4 x 60.0 x 66.0

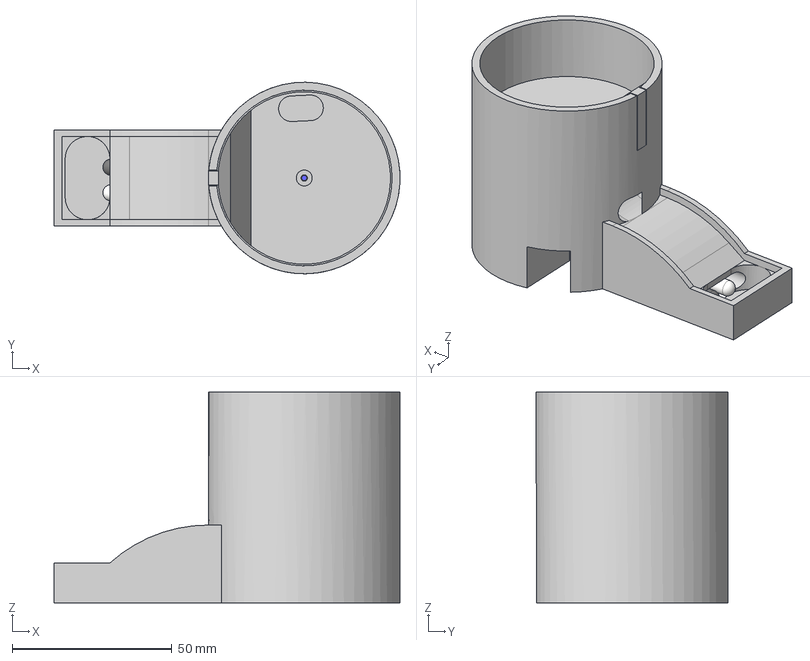
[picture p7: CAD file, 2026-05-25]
Hardware/Dispensador.step
108.3 x 60.0 x 66.0 mm
SG90 - Micro Servo 9g - Tower Pro.1_Pea
Base
Rotador TicTac
Bloqueo
Komponente1

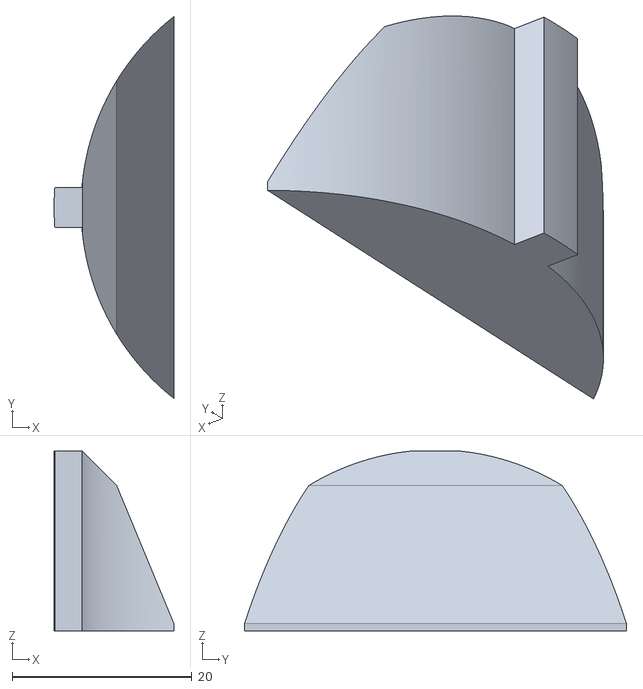
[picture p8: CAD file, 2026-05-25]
Hardware/Archivos STL/Bloqueo.stl
13.3 x 42.5 x 20.0

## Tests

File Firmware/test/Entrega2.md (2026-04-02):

# Requisitos funcionales y no funcionales del sistema, plan de testing y pruebas para los requerimientos

## Requerimientos funcionales

### RF-01 — Programar hasta cuatro horarios diarios desde la GUI
El sistema debe permitir programar hasta cuatro horarios de dispensación diarios desde la interfaz gráfica táctil. Este requerimiento es fundamental porque un paciente con enfermedad crónica puede requerir múltiples tomas a lo largo del día en horarios distintos. El límite de cuatro horarios cubre la mayoría de esquemas farmacológicos habituales sin sobrecomplicar la interfaz. Al hacerlo configurable desde la pantalla táctil, se garantiza que el propio paciente o su cuidador pueda ajustar los horarios sin necesidad de herramientas externas ni conocimientos técnicos.

#### Objetivo
Verificar que el sistema permite al usuario configurar hasta cuatro horarios de dispensación diarios distintos desde la pantalla táctil, y que estos quedan correctamente almacenados y activos en el sistema.

#### Precondiciones
- El sistema está encendido y la pantalla ILI9341 responde al tacto.
- No hay horarios previamente configurados.
- El RTC DS3231 está sincronizado con hora real.

#### Resultado esperado
El sistema acepta y almacena correctamente hasta 4 horarios distintos configurados desde la pantalla táctil.

#### Prueba para el requerimiento
1) Programar 4 horarios desde la GUI
2) Guardar configuración
3) Apagar el sistema
4) Encender nuevamente
5) Verificar:
- Los horarios siguen almacenados
- Son correctos
- El sistema los usa para dispensar

#### Validación
1) El sistema almacena exactamente 4 horarios.
2) Tras reinicio, los horarios siguen iguales.

---

### RF-02 — Dispensar automáticamente en el horario programado
El sistema debe dispensar automáticamente la dosis programada cuando el horario configurado se cumpla. La automatización de la dispensación elimina la dependencia de la memoria del paciente, que es precisamente el eslabón más débil en el cumplimiento de tratamientos crónicos. Al delegar esta responsabilidad al sistema embebido con una referencia temporal precisa, se garantiza que la medicación esté disponible en el momento exacto indicado por el médico, independientemente del estado cognitivo o de la rutina del paciente.

#### Objetivo
Verificar que el mecanismo de dispensación se activa de forma autónoma cuando el reloj del sistema alcanza el horario configurado, sin intervención del usuario.

#### Precondiciones
- Al menos un horario de dispensación está configurado en el sistema.
- El RTC DS3231 está sincronizado y funcionando correctamente.
- El compartimento tiene al menos una pastilla cargada.
- El mecanismo físico de dispensación está ensamblado y operativo.

#### Resultado esperado
El mecanismo de dispensación se activa dentro del margen de ±1 minuto del horario configurado.

#### Prueba para el requerimiento
1) Configurar horario cercano
2) Medir tiempo real vs Activación

#### Validación
1) Diferencia + o – 1 min (se usa cronómetro)

---

### RF-03 — Detectar si la pastilla fue dispensada correctamente
El sistema debe detectar mediante un sensor si la pastilla fue efectivamente dispensada al exterior del compartimento. Verificar que la dispensación ocurrió realmente es crítico para la seguridad del paciente. Un mecanismo de dispensación puede activarse sin que la pastilla haya salido debido a un atasco, desgaste mecánico o compartimento vacío. Sin esta verificación el sistema no tendría forma de distinguir entre una dispensación exitosa y un fallo, lo que podría llevar al paciente a creer que su dosis fue suministrada cuando en realidad no lo fue.

#### Objetivo
Verificar que el sensor de presencia detecta correctamente si una pastilla salió del compartimento tras un ciclo de dispensación, distinguiendo entre una dispensación exitosa y un fallo mecánico.

#### Precondiciones
- El sensor de presencia está instalado en la posición correcta y verificado individualmente.
- El mecanismo de dispensación está operativo.
- Se dispone de pastillas de prueba de tamaño representativo.
- El compartimento está cargado con al menos una pastilla.

#### Resultado esperado
El sensor detecta presencia/ausencia de pastilla y el sistema distingue entre dispensación exitosa y fallo.

#### Prueba para el requerimiento
1) Simular dispensación normal
2) Bloquear salida (atasco)
3) Quitar pastilla (compartimento vacío)

#### Validación
1) Sensor detecta:
- OK → INFO
- Falla → ERROR

---

### RF-04 — Alerta si el usuario no recoge la pastilla
El sistema debe emitir una alerta sonora y visual cuando el usuario no recoja la pastilla dentro de un tiempo límite configurado. Que la pastilla esté disponible no garantiza que el paciente la tome, especialmente en adultos mayores que pueden estar distraídos, dormidos o con dificultades de movilidad. La alerta actúa como un recordatorio activo que persiste hasta que el paciente responda. Combinar señal sonora y visual aumenta la probabilidad de que el paciente perciba la notificación sin importar sus condiciones sensoriales o el entorno en el que se encuentre.

#### Objetivo
Verificar que el sistema activa la alerta sonora y visual cuando transcurre el tiempo límite configurado sin que el usuario haya retirado la pastilla dispensada.

#### Precondiciones
- RF-02 y RF-03 funcionan correctamente (la pastilla fue dispensada y detectada).
- El buzzer y el LED están conectados y verificados individualmente.
- El tiempo límite de espera está configurado en el firmware.
- El usuario no interactúa con el dispositivo durante la prueba.

#### Resultado esperado
El buzzer y el LED se activan después del tiempo límite si la pastilla no ha sido retirada.

#### Prueba para el requerimiento
1) Dispensar
2) No retirar pastilla

#### Validación
1) Led y buzzer se activan después de un tiempo

---

### RF-05 — Detectar compartimento vacío antes de dispensar
El sistema debe detectar si el compartimento de medicamentos está vacío antes de intentar realizar una dispensación. Intentar dispensar sobre un compartimento vacío puede dañar el mecanismo físico del dispositivo y genera un evento de fallo que podría confundirse con una dispensación exitosa. Detectar esta condición antes de actuar permite al sistema tomar una decisión informada: en lugar de ejecutar un ciclo de dispensación inútil, puede notificar el problema de forma inmediata y precisa, protegiendo tanto al dispositivo como al paciente.

#### Objetivo
Verificar que el sistema detecta la ausencia de pastillas en el compartimento antes de ejecutar el ciclo de dispensación, y que cancela la operación sin activar el mecanismo físico.

#### Precondiciones
- El compartimento está vacío antes de iniciar la prueba.
- El sensor de detección de compartimento vacío está instalado y verificado.
- Hay al menos un horario de dispensación configurado y próximo a ejecutarse.

#### Resultado esperado
El sistema detecta compartimento vacío y cancela el ciclo de dispensación antes de ejecutarlo.

#### Prueba para el requerimiento
1) Vaciar compartimento
2) Forzar evento de dispensación

#### Validación
1) No se activa motor
2) Se genera alerta

---

### RF-06 — Alertar cuando el compartimento esté vacío
El sistema debe emitir una alerta sonora y visual cuando el compartimento de medicamentos esté vacío. Un compartimento vacío sin notificación significa que el dispositivo seguirá intentando dispensar en cada horario programado sin éxito, y el paciente no recibirá su medicación sin saber por qué. La alerta garantiza que el paciente o su cuidador sean informados oportunamente para recargar el dispensador antes de que se pierda una toma, manteniendo la continuidad del tratamiento.

#### Objetivo
Verificar que el sistema emite una alerta sonora y visual al detectar que el compartimento no tiene pastillas, notificando al usuario o cuidador para que proceda a recargarlo.

#### Precondiciones
- El compartimento está vacío.
- El buzzer y el LED están conectados y operativos.
- El sistema tiene al menos un horario configurado que desencadena la revisión del compartimento.

#### Resultado esperado
Se emite alerta sonora y visual al detectar compartimento vacío.

#### Prueba para el requerimiento
1) Activar condición de vacío manualmente

#### Validación
1) LED + buzzer + log WARN/ERROR

---

### RF-07 — Registrar eventos con marca temporal
El sistema debe registrar cada evento relevante como dispensaciones, alertas y errores, mediante un esquema de logging estructurado con marca temporal. El registro de eventos con hora exacta permite reconstruir el comportamiento del sistema en cualquier momento posterior. Esto es valioso tanto para el cuidador que quiere verificar si el paciente tomó su medicación, como para el desarrollador que necesita depurar un comportamiento inesperado. Sin trazabilidad temporal, cualquier análisis del funcionamiento del sistema se vuelve especulativo e inútil en contextos clínicos.

#### Objetivo
Verificar que cada evento relevante del sistema (dispensación, alerta, error) queda registrado vía UART con un timestamp que corresponde a la hora real provista por el RTC DS3231.

#### Precondiciones
- El RTC DS3231 está sincronizado con hora real antes de iniciar la prueba.
- El puerto UART está conectado a un monitor serial en el PC y configurado a la velocidad de baudios correcta.
- El sistema tiene al menos un horario configurado para generar eventos observables.

#### Resultado esperado
Cada evento queda registrado vía UART con timestamp correcto del RTC DS3231.

#### Prueba para el requerimiento
1) Ejecutar eventos
2) Leer UART

#### Validación
1) Timestamp coincide con RTC

---

### RF-08 — Clasificar el log con niveles de severidad
El sistema debe clasificar cada entrada del log con un nivel de severidad: INFO, WARN o ERROR. Clasificar los eventos por severidad hace el log consultable y accionable. Permite filtrar rápidamente los eventos que requieren atención inmediata sin tener que revisar toda la historia de operación normal. Un operador o cuidador puede enfocarse en los niveles de mayor severidad para identificar problemas, mientras que los registros informativos documentan el funcionamiento correcto del sistema a lo largo del tiempo.

#### Objetivo
Verificar que cada entrada del log contiene el nivel de severidad correcto (INFO, WARN o ERROR) según el tipo de evento que lo generó, permitiendo distinguir el comportamiento normal del sistema de sus condiciones de fallo.

#### Precondiciones
- El monitor serial está activo y registrando la salida UART.
- El sistema puede generar los tres tipos de eventos: operación normal (INFO), condición de advertencia como compartimento vacío (WARN) y fallo de dispensación (ERROR).
- RF-07 funciona correctamente.

#### Resultado esperado
Cada entrada del log contiene el nivel correspondiente: INFO, WARN o ERROR según el tipo de evento.

#### Prueba para el requerimiento
1) Generar eventos de cada tipo

#### Validación
1) INFO/WARN/ERROR correctamente asignados

---

### RF-09 — Mostrar hora, horarios configurados y estado en pantalla
El sistema debe mostrar en la pantalla táctil la hora actual, los horarios configurados y el estado del compartimento. El paciente necesita tener visibilidad permanente del estado del sistema sin depender de herramientas externas. Ver la hora actual le permite orientarse temporalmente, ver los horarios programados le recuerda cuándo esperar la próxima dosis, y conocer el estado del compartimento le indica si debe recargarlo. Concentrar esta información en la pantalla convierte al dispositivo en una fuente confiable de información de salud para el usuario.

#### Objetivo
Verificar que la pantalla táctil ILI9341 muestra en tiempo real y de forma legible la hora actual, los horarios de dispensación configurados y el estado del compartimento, sin necesidad de interacción adicional del usuario.

#### Precondiciones
- La pantalla ILI9341 está conectada y funcional vía SPI.
- El RTC DS3231 está sincronizado y proveyendo la hora correcta.
- Al menos un horario está configurado en el sistema.
- El compartimento tiene un estado definido (lleno o vacío) verificable visualmente.

#### Resultado esperado
La pantalla muestra en tiempo real la hora actual, horarios configurados y estado del compartimento.

#### Prueba para el requerimiento
1) Comparar GUI vs valores internos

#### Validación
1) Datos coinciden con sistema

---

### RF-10 — Modificar o eliminar horarios desde la GUI
El sistema debe permitir modificar o eliminar horarios de dispensación previamente configurados desde la interfaz gráfica. Los tratamientos médicos no son estáticos: los médicos ajustan dosis, frecuencias y horarios a lo largo del tiempo según la evolución del paciente. Un sistema que no permita actualizar la configuración pierde utilidad práctica muy rápidamente y obliga a intervenciones técnicas para cada cambio, lo cual es inaceptable para el perfil de usuario al que está dirigido el dispositivo.

#### Objetivo
Verificar que el sistema permite editar o eliminar un horario previamente configurado desde la pantalla táctil, y que el cambio se refleja de inmediato tanto en la visualización como en el comportamiento de dispensación.

#### Precondiciones
- Al menos un horario está previamente configurado en el sistema.
- La pantalla táctil responde correctamente al tacto.
- El RTC DS3231 está activo y el sistema está en ciclo de operación normal.

#### Resultado esperado
El sistema actualiza o elimina correctamente un horario y el cambio se refleja en pantalla y comportamiento.

#### Prueba para el requerimiento
1) Crear horario
2) Modificarlo
3) Eliminarlo
4) Esperar evento

#### Validación
1) Sistema responde al cambio en tiempo real

---

## Requerimientos no funcionales

### RNF-01 — Respuesta a entrada táctil en menos de 500 ms
El sistema debe responder a cualquier entrada del usuario en la pantalla táctil en menos de 500 ms. La velocidad de respuesta de la interfaz determina directamente si el usuario percibe el dispositivo como funcional o defectuoso. Una respuesta lenta genera desconfianza, especialmente en adultos mayores que pueden interpretar la demora como un error y repetir la acción, generando interacciones no deseadas. Mantener este umbral de respuesta garantiza una experiencia de uso natural y confiable para el perfil de usuario del dispositivo.

#### Objetivo
Verificar que el tiempo transcurrido entre cualquier toque en la pantalla táctil y la respuesta visual del sistema no supera los 500 ms, garantizando una experiencia de uso natural para el perfil de usuario del dispositivo.

#### Precondiciones
- La pantalla ILI9341 está conectada y operativa.
- Se dispone de un método de medición de tiempo (cronómetro, osciloscopio o lógica de timestamps en firmware).
- El sistema está en operación normal, no en un ciclo de dispensación activo.

#### Resultado esperado
Desde el toque hasta la respuesta visual transcurren menos de 500 ms en todas las interacciones.

#### Prueba para el requerimiento
1) Medir con cronómetro o logs

#### Validación
1) Tiempo <= 500 ms

---

### RNF-02 — Precisión temporal máxima de ±1 minuto
El sistema debe mantener una precisión temporal máxima de ±1 minuto respecto a la hora programada. En tratamientos farmacológicos crónicos el horario de administración puede tener implicaciones clínicas directas, particularmente en medicamentos cuya efectividad depende de mantener niveles estables en el organismo. Una desviación mayor podría comprometer la eficacia del tratamiento o generar efectos no deseados, por lo que contar con una referencia temporal confiable es un aspecto no negociable del sistema.

#### Objetivo
Verificar que la dispensación se ejecuta dentro de un margen de ±60 segundos respecto a la hora programada, en múltiples ciclos de prueba consecutivos, validando la confiabilidad del RTC DS3231 como referencia temporal.

#### Precondiciones
- El RTC DS3231 está sincronizado con una fuente de hora confiable antes de iniciar.
- Al menos un horario de dispensación está configurado y se conoce la hora exacta programada.
- Se dispone de un reloj de referencia externo para comparar el momento real de la dispensación.

#### Resultado esperado
La dispensación no se desvía más de 60 segundos respecto a la hora programada en ningún ciclo.

#### Prueba para el requerimiento
1) Comparar RTC vs reloj externo por varios minutos

#### Validación
1) Error <= 1 min

---

### RNF-03 — Firmware modular con manejo de errores y documentación
El firmware debe estar estructurado en módulos independientes con manejo explícito de errores y documentación en el código. Un sistema embebido destinado al cuidado de la salud debe ser mantenible, auditable y robusto. La modularidad permite aislar fallos, facilita las pruebas de cada componente y hace posible que cualquier miembro del equipo entienda y modifique una parte del sistema sin afectar las demás. El manejo explícito de errores asegura que ningún fallo quede silencioso ni cause comportamientos impredecibles.

#### Objetivo
Verificar que el firmware está organizado en módulos independientes, que cada módulo maneja sus propios errores sin propagar fallos al resto del sistema, y que el código cuenta con documentación suficiente para ser comprensible por cualquier miembro del equipo.

#### Precondiciones
- El código fuente del firmware está disponible para revisión.
- Se puede acceder al monitor serial para observar el comportamiento del sistema ante fallos inducidos.
- Se dispone de criterios de revisión definidos: separación de módulos, comentarios en funciones clave y ausencia de fallos silenciosos.

#### Resultado esperado
El código está dividido en módulos independientes; cada error queda capturado sin colapsar el sistema.

#### Prueba para el requerimiento
1) Revisión de código

#### Validación
1) Separación en módulos:
- GUI
- RTC
- Dispensador
- Sensores

---

### RNF-04 — Operación continua sin reinicio manual
El sistema debe operar de forma continua sin requerir reinicio manual, tolerando condiciones de fallo sin detener su ciclo de operación normal. El dispositivo opera en el hogar de un paciente que en muchos casos vive solo y no cuenta con asistencia técnica permanente. Un sistema que se bloquea ante un error obliga a una intervención externa que puede no ocurrir a tiempo, resultando en tomas de medicación perdidas. La resiliencia operacional no es una característica deseable sino un requisito de seguridad para este tipo de aplicación.

#### Objetivo
Verificar que el sistema es capaz de recuperarse de condiciones de fallo como compartimento vacío o dispensación fallida, y continuar su ciclo de operación normal sin requerir intervención externa ni reinicio del dispositivo.

#### Precondiciones
- El sistema lleva encendido un tiempo suficiente para haber ejecutado al menos un ciclo completo.
- Se pueden inducir condiciones de fallo de forma controlada (vaciar el compartimento, bloquear el mecanismo momentáneamente).
- El monitor serial está activo para observar cómo el sistema registra y responde al fallo.

#### Resultado esperado
El sistema se recupera de condiciones de fallo y continúa su ciclo normal sin intervención externa.

#### Prueba para el requerimiento
1) Simular fallos:
- Sensor desconectado
- Compartimento vacío
2) Ejecutar durante varias horas

#### Validación
1) Sistema no se detiene

---

## Artefactos a usar

1) Monitor serial (UART)
2) Cronómetro
3) Multímetro
4) Cámara
5) Logs guardados
6) Scripts

## Tipos de test

### Pruebas unitarias (Prueba de una sola pieza aislada del sistema)
1) Leer hora del RTC (DS3231)
2) Detectar si el sensor cambia de estado
3) Encender/apagar buzzer
4) Dibujar algo en la pantalla

### Pruebas de integración (Prueba de interacción de módulos juntos)
1) Configuras horario en GUI
2) Se guarda en memoria
3) RTC llega a la hora
4) Se activa dispensación

### Pruebas de sistema (Se prueba como lo ejecutaría el usuario)
1) Usuario configura horarios
2) Espera
3) Sistema dispensa
4) Usuario recoge
5) Se registra en log

### Pruebas de fallo (Probar lo que pasa cuando las cosas salen mal)
1) Compartimento vacío
2) Pastilla atascada
3) Usuario no recoge
4) Sensor desconectado
5) RTC falla

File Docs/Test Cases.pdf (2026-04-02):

### Requerimiento Funcional

TC-001

En proceso

Trazabilidad del requerimiento | RF - 01: Programar cuatro horarios diarios desde la GUI
Objetivo de la prueba | Verificar que el sistema permite al usuario configurar hasta cuatro horarios de dispensación diarios distintos desde la pantalla táctil, y que estos quedan correctamente almacenados y activos en el sistema.
Precondiciones | El sistema está encendido y la pantalla ILI9341 responde al tacto. No hay horarios previamente configurados. El RTC DS3231 está sincronizado con hora real.
Resultados esperados Resultados esperados | | Resultados reales Resultados reales

### Evidencia

El sistema acepta y almacena correctamente hasta 4 horarios distintos configurados desde la pantalla táctil.

Evidencia

### Requerimiento Funcional

TC-002

En proceso

Trazabilidad del requerimiento | RF - 02: Dispensar automáticamente en el horario programado
Objetivo de la prueba | Verificar que el mecanismo de dispensación se activa de forma autónoma cuando el reloj del sistema alcanza el horario configurado, sin intervención del usuario.
Precondiciones | Al menos un horario de dispensación configurado en el sistema. El RTC DS3231 está sincronizado y funcionando correctamente. El compartimento tiene al menos una pastilla cargada. El mecanismo físico de dispensación está ensamblado y operativo.
Resultados esperados | Resultados reales

### Evidencia

El mecanismo de dispensación se activa dentro del margen de ±1 minuto del horario configurado.

Evidencia

### Requerimiento Funcional

TC-003

En proceso

Trazabilidad del requerimiento | RF - 03: Detectar si la pastilla fue dispensada correctamente
Objetivo de la prueba | Verificar que el sensor de presencia detecta correctamente si una pastilla salió del compartimento tras un ciclo de dispensación, distinguiendo entre una dispensación exitosa y un fallo mecánico.
Precondiciones Resultados esperados | Sensor de presencia está en la posición correcta y verificado. El mecanismo de dispensación está operativo. Se dispone de pastillas de prueba de tamaño representativo. El compartimento está cargado con al menos una pastilla. Resultados reales
Resultados esperados | Resultados reales

### Evidencia

El sensor detecta presencia/ausencia de pastilla y el sistema distingue entre dispensación exitosa y fallo.

Evidencia

### Requerimiento Funcional

TC-004

En proceso

Trazabilidad del requerimiento | RF - 04: Alerta si el usuario no recoge la pastilla
Objetivo de la prueba | Verificar que el sistema activa la alerta sonora y visual cuando transcurre el tiempo límite configurado sin que el usuario haya retirado la pastilla dispensada.
Precondiciones Resultados esperados | RF-02 y RF-03 funcionan correctamente. El buzzer y el LED están conectados y verificados individualmente. El tiempo límite de espera está configurado en el firmware. El usuario no interactúa con el dispositivo durante la prueba. Resultados reales
Resultados esperados | Resultados reales

### Evidencia

El buzzer y el LED se activan después del tiempo límite si la pastilla no ha sido retirada.

Evidencia

### Requerimiento Funcional

TC-005

En proceso

Trazabilidad del requerimiento | RF - 05: Detectar compartimento vacío antes de dispensar
Objetivo de la prueba | Verificar que el sistema detecta la ausencia de pastillas en el compartimento antes de ejecutar el ciclo de dispensación, y que cancela la operación sin activar el mecanismo físico.
Precondiciones | El compartimento está vacío antes de iniciar la prueba. Sensor de detección de compartimento vacío instalado y verificado. Hay al menos un horario de dispensación configurado próximo.
Resultados esperados Resultados esperados | | Resultados reales Resultados reales

### Evidencia

El sistema detecta compartimento vacío y cancela el ciclo de dispensación antes de ejecutarlo.

Evidencia

### Requerimiento Funcional

TC-006

En proceso

Trazabilidad del requerimiento | RF - 06: Alertar cuando el compartimento de medicamento esté vacío
Objetivo de la prueba | Verificar que el sistema emite una alerta sonora y visual al detectar que el compartimento no tiene pastillas, notificando al usuario o cuidador para que proceda a recargarlo.
Precondiciones | El compartimento de medicamento está vacío. El buzzer y el LED están conectados y operativos. El sistema tiene al menos un horario configurado que desencadena la revisión del compartimento.
Resultados esperados | Resultados reales

### Evidencia

Se emite alerta sonora y visual al detectar compartimento vacío.

Evidencia

### Requerimiento Funcional

TC-007

En proceso

Trazabilidad del requerimiento | RF - 07: Registrar eventos con marca temporal
Objetivo de la prueba | Verificar que cada evento relevante del sistema (dispensación, alerta, error) queda registrado vía UART con un timestamp que corresponde a la hora real provista por el RTC DS3231.
Precondiciones | RTC DS3231 está sincronizado con hora real antes de iniciar la prueba. El puerto UART está conectado a un monitor serial en el PC y configurado a la velocidad de baudios correcta. Sistema tiene horario configurado para generar eventos observables.
Resultados esperados | Resultados reales

### Evidencia

Se emite alerta sonora y visual al detectar compartimento vacío.

Evidencia

### Requerimiento Funcional

TC-008

En proceso

Trazabilidad del requerimiento | RF - 08: Clasificar el log con niveles de severidad
Objetivo de la prueba | Verificar que cada entrada del log contiene el nivel de severidad correcto (INFO, WARN o ERROR) según el tipo de evento que lo generó, permitiendo distinguir el comportamiento normal del sistema de sus condiciones de fallo.
Precondiciones | El monitor serial está activo y registrando la salida UART. El sistema puede generar los tres tipos de eventos: operación normal (INFO), condición de advertencia como compartimento vacío (WARN) y fallo de dispensación (ERROR). RF-07 funciona correctamente.
Resultados esperados | Resultados reales

### Evidencia

Cada entrada del log contiene el nivel correspondiente: INFO, WARN o ERROR según el tipo de evento.

Evidencia

### Requerimiento Funcional

TC-009

En proceso

Trazabilidad del requerimiento | RF - 09: Mostrar hora, horarios configurados y estado en pantalla
Objetivo de la prueba | Verificar que la pantalla táctil ILI9341 muestra en tiempo real y de forma legible la hora actual, los horarios de dispensación configurados y el estado del compartimento, sin necesidad de interacción adicional del usuario.
Precondiciones | La pantalla ILI9341 está conectada y funcional vía SPI. El RTC DS3231 está sincronizado y proveyendo la hora correcta. Al menos un horario está configurado en el sistema. El compartimento tiene un estado definido (lleno o vacío) verificable visualmente.
Resultados esperados | Resultados reales

### Evidencia

La pantalla muestra en tiempo real la hora actual, horarios configurados y estado del compartimento.

Evidencia

### Requerimiento Funcional

TC-010

En proceso

Trazabilidad del requerimiento | RF - 10: Modificar o eliminar horarios desde la GUI
Objetivo de la prueba | Verificar que el sistema permite editar o eliminar un horario previamente configurado desde la pantalla táctil, y que el cambio se refleja de inmediato tanto en la visualización como en el comportamiento de dispensación.
Precondiciones | Al menos un horario está previamente configurado en el sistema. La pantalla táctil responde correctamente al tacto. El RTC DS3231 está activo y el sistema está en ciclo de operación normal.
Resultados esperados | Resultados reales

### Evidencia

El sistema actualiza o elimina correctamente un horario y el cambio se refleja en pantalla y comportamiento.

Evidencia

Trazabilidad del requerimiento | RNF - 01: Respuesta a entrada táctil en menos de 500 ms
Objetivo de la prueba | Verificar que el tiempo transcurrido entre cualquier toque en la pantalla táctil y la respuesta visual del sistema no supera los 500 ms, garantizando una experiencia de uso natural para el perfil de usuario del dispositivo.
Precondiciones | La pantalla ILI9341 está conectada y operativa. Se dispone de un método de medición de tiempo (cronómetro, osciloscopio o lógica de timestamps en firmware). El sistema está en operación normal, no en un ciclo de dispensación activo.
Resultados esperados | Resultados reales

TC-011

En proceso

### Evidencia

Desde el toque hasta la respuesta visual transcurren menos de 500 ms en todas las interacciones.

### Requerimiento No Funcional

Evidencia

TC-012

En proceso

Trazabilidad del requerimiento | RNF - 02: Precisión temporal máxima de ±1 minuto
Objetivo de la prueba | Verificar que la dispensación se ejecuta dentro de un margen de ±60 segundos respecto a la hora programada, en múltiples ciclos de prueba consecutivos, validando la confiabilidad del RTC DS3231 como referencia temporal.
Precondiciones | El RTC DS3231 está sincronizado con una fuente de hora confiable. Al menos un horario de dispensación está configurado y se conoce la hora exacta programada. Se dispone de un reloj de referencia externo para comparar el momento real de la dispensación.
Resultados esperados | Resultados reales

### Evidencia

La dispensación no se desvía más de 60 segundos respecto a la hora programada en ningún ciclo.

### Requerimiento No Funcional

Evidencia

TC-013

En proceso

Trazabilidad del requerimiento | RNF - 03: Firmware modular con manejo de errores y documentación
Objetivo de la prueba | Verificar que el firmware está organizado en módulos independientes, que cada módulo maneja sus propios errores sin propagar fallos al resto del sistema, y que el código cuenta con documentación suficiente.
Precondiciones | El código fuente del firmware está disponible para revisión. Se puede acceder al monitor serial para observar el comportamiento del sistema ante fallos inducidos. Se dispone de criterios de revisión definidos: separación de módulos, comentarios en funciones clave y ausencia de fallos silenciosos.
Resultados esperados | Resultados reales

### Evidencia

El código está dividido en módulos independientes; cada error queda capturado sin colapsar el sistema.

### Requerimiento No Funcional

Evidencia

### Requerimiento No Funcional

TC-014

En proceso

Trazabilidad del requerimiento | RNF - 04: Operación continua sin reinicio manual
Objetivo de la prueba | Verificar que el sistema es capaz de recuperarse de condiciones de fallo como compartimento vacío o dispensación fallida, y continuar su ciclo de operación normal sin requerir intervención externa ni reinicio del dispositivo.
Precondiciones | El sistema lleva encendido un tiempo suficiente para haber ejecutado al menos un ciclo completo. Se pueden inducir condiciones de fallo de forma controlada (vaciar el compartimento, bloquear el mecanismo momentáneamente). El monitor serial está activo para observar cómo el sistema registra y responde al fallo.
Resultados esperados | Resultados reales

El sistema se recupera de condiciones de fallo y continúa su ciclo normal sin intervención externa.

Evidencia

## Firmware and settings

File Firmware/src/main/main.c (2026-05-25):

#define SERVO_GPIO_T1   14
#define SERVO_GPIO_T2   27
#define SERVO_GPIO_T3   16
#define SERVO_GPIO_T4   17
 
#define IR_BAND_T1      36
#define IR_BAND_T2      39
#define IR_BAND_T3      25
#define IR_BAND_T4      26
 
#define PIN_BUZZER      13
#define PIN_LED         12
 
#define PIN_SDA         21
#define PIN_SCL         22
#define DS3231_ADDR     0x68
#define I2C_PORT        I2C_NUM_0
 
#define UART_NUM_CFG    UART_NUM_0
#define UART_BAUD_CFG   115200
#define UART_BUF        512
 
#define UART_NUM_NEXTION UART_NUM_1
#define NEXTION_TX_GPIO  5   // ESP32 TX -> Nextion RX
#define NEXTION_RX_GPIO  4   // ESP32 RX <- Nextion TX
#define NEXTION_BAUD     9600
#define NEXTION_BUF      512
 
// PARAMETROS
 
#define MAX_TUBOS               4
#define SERVO_FREQ_HZ           50
#define SERVO_MIN_US            600
#define SERVO_MAX_US            1800
#define SERVO_ANGULO_ABIERTO    180
#define SERVO_ANGULO_CERRADO    0
#define SERVO_MS_ACCION         1000
#define TIMEOUT_CAIDA_MS        3000
#define TIMEOUT_RECOGIDA_MS     60000
#define ERROR_ALARMA_MS         15000
#define MAX_REINTENTOS_CAIDA    4
#define DEBOUNCE_COUNT          3
#define TICK_SCHEDULER_MS       1000
#define TICK_MONITOR_MS         7000
#define TICK_NEXTION_MS         1500
#define MAX_LOGS                5
#define LOG_LEN                 120
 
// FC-51 tipico: LOW = objeto detectado. Si tu sensor trabaja al reves, pon 0.
#define SENSOR_ACTIVO_EN_LOW    1
 
// ESTRUCTURAS
 
typedef enum {
    TUBO_OK = 0,
    TUBO_DISPENSANDO,
    TUBO_FALLO,
} estado_tubo_t;
 
typedef struct {
    bool activo;
    int  hora;
    int  minuto;
    int  cantidad;
} horario_t;
 
typedef struct {
    estado_tubo_t estado;
    bool          pastilla_en_bandeja;
    bool          alerta_activa;   // true para dosis lista o error no confirmado
} info_tubo_t;
 
// VARIABLES GLOBALES
 
static const char *TAG = "SMARTDOSE";
 
static const int SERVO_GPIOS[MAX_TUBOS] = {
    SERVO_GPIO_T1, SERVO_GPIO_T2, SERVO_GPIO_T3, SERVO_GPIO_T4
};
 
static const int IR_BAND_GPIOS[MAX_TUBOS] = {
    IR_BAND_T1, IR_BAND_T2, IR_BAND_T3, IR_BAND_T4
};
 
static horario_t   g_horarios[MAX_TUBOS];
static info_tubo_t g_info[MAX_TUBOS];
static SemaphoreHandle_t g_mutex;
static int g_ultimo_minuto[MAX_TUBOS];
static char g_logs[MAX_LOGS][LOG_LEN];
 
// UTILIDADES
 
static int64_t millis(void)
{
    return esp_timer_get_time() / 1000;
}
 
// SERVO
 
static uint32_t angulo_a_duty(int angulo)
{
    if (angulo < 0) angulo = 0;
    if (angulo > 180) angulo = 180;
    uint32_t us = SERVO_MIN_US + (uint32_t)((SERVO_MAX_US - SERVO_MIN_US) * angulo / 180);
    return (us * 16383U) / 20000U;
}
 
static void servo_set(int idx, int angulo)
{
    if (idx < 0 || idx >= MAX_TUBOS) return;
    ledc_channel_t ch = (ledc_channel_t)(LEDC_CHANNEL_0 + idx);
    ledc_set_duty(LEDC_HIGH_SPEED_MODE, ch, angulo_a_duty(angulo));
    ledc_update_duty(LEDC_HIGH_SPEED_MODE, ch);
}
 
static void servo_dispensar(int idx, int cantidad)
{
    if (cantidad < 1) cantidad = 1;
    if (cantidad > 10) cantidad = 10;
 
    for (int v = 0; v < cantidad; v++) {
        servo_set(idx, SERVO_ANGULO_ABIERTO);
        vTaskDelay(pdMS_TO_TICKS(SERVO_MS_ACCION));
        servo_set(idx, SERVO_ANGULO_CERRADO);
        vTaskDelay(pdMS_TO_TICKS(SERVO_MS_ACCION));
    }
}
 
// SENSOR DE BANDEJA
 
static bool sensor_leer(int gpio)
{
    int detectado = 0;
    for (int i = 0; i < DEBOUNCE_COUNT; i++) {
        int level = gpio_get_level(gpio);
#if SENSOR_ACTIVO_EN_LOW
        if (level == 0) detectado++;
#else
        if (level == 1) detectado++;
#endif
        vTaskDelay(pdMS_TO_TICKS(10));
    }
    return detectado > (DEBOUNCE_COUNT / 2);
}
 
static bool bandeja_tiene_pastilla(int idx)
{
    if (idx < 0 || idx >= MAX_TUBOS) return false;
    return sensor_leer(IR_BAND_GPIOS[idx]);
}
 
// ALERTAS
 
static void buzzer_set(bool on) { gpio_set_level(PIN_BUZZER, on ? 1 : 0); }
static void led_set(bool on)    { gpio_set_level(PIN_LED,    on ? 1 : 0); }
 
// RTC DS3231
 
static uint8_t bcd2dec(uint8_t b) { return (uint8_t)((b >> 4) * 10 + (b & 0x0F)); }
static uint8_t dec2bcd(uint8_t d) { return (uint8_t)(((d / 10) << 4) | (d % 10)); }
 
static bool ds3231_set_hora(int h, int m, int s)
{
    uint8_t data[3];
    data[0] = dec2bcd((uint8_t)s);
    data[1] = dec2bcd((uint8_t)m);
    data[2] = dec2bcd((uint8_t)h);
 
    i2c_cmd_handle_t cmd = i2c_cmd_link_create();
    i2c_master_start(cmd);
    i2c_master_write_byte(cmd, (DS3231_ADDR << 1) | I2C_MASTER_WRITE, true);
    i2c_master_write_byte(cmd, 0x00, true);
    i2c_master_write(cmd, data, 3, true);
    i2c_master_stop(cmd);
 
    esp_err_t err = i2c_master_cmd_begin(I2C_PORT, cmd, pdMS_TO_TICKS(100));
    i2c_cmd_link_delete(cmd);
    return err == ESP_OK;
}
 
static bool ds3231_leer(uint8_t reg, uint8_t *buf, int len)
{
    if (!buf || len <= 0) return false;
 
    i2c_cmd_handle_t cmd = i2c_cmd_link_create();
    i2c_master_start(cmd);
    i2c_master_write_byte(cmd, (DS3231_ADDR << 1) | I2C_MASTER_WRITE, true);
    i2c_master_write_byte(cmd, reg, true);
    i2c_master_start(cmd);
    i2c_master_write_byte(cmd, (DS3231_ADDR << 1) | I2C_MASTER_READ, true);
    if (len > 1) i2c_master_read(cmd, buf, len - 1, I2C_MASTER_ACK);
    i2c_master_read_byte(cmd, &buf[len - 1], I2C_MASTER_NACK);
    i2c_master_stop(cmd);
 
    esp_err_t err = i2c_master_cmd_begin(I2C_PORT, cmd, pdMS_TO_TICKS(100));
    i2c_cmd_link_delete(cmd);
    return err == ESP_OK;
}
 
static bool ds3231_get_hora(int *h, int *m, int *s)
{
    uint8_t buf[3];
    if (!ds3231_leer(0x00, buf, 3)) return false;
    if (s) *s = bcd2dec(buf[0] & 0x7F);
    if (m) *m = bcd2dec(buf[1] & 0x7F);
    if (h) *h = bcd2dec(buf[2] & 0x3F);
    return true;
}
 
// NEXTION
 
static void nextion_write_raw(const char *s)
{
    if (!s) return;
    uart_write_bytes(UART_NUM_NEXTION, s, strlen(s));
    const uint8_t end[3] = {0xFF, 0xFF, 0xFF};
    uart_write_bytes(UART_NUM_NEXTION, (const char *)end, 3);
}
 
static void nextion_cmd(const char *fmt, ...)
{
    char cmd[180];
    va_list ap;
    va_start(ap, fmt);
    vsnprintf(cmd, sizeof(cmd), fmt, ap);
    va_end(ap);
    nextion_write_raw(cmd);
}
 
static void nextion_set_txt(const char *obj, const char *txt)
{
    if (!obj || !txt) return;
    char safe[120];
    size_t k = 0;
    for (size_t i = 0; txt[i] && k < sizeof(safe) - 1; i++) {
        if (txt[i] == '"') continue;
        safe[k++] = txt[i];
    }
    safe[k] = '\0';
    nextion_cmd("%s.txt=\"%s\"", obj, safe);
}
 
static void nextion_set_val(const char *obj, int value)
{
    if (!obj) return;
    nextion_cmd("%s.val=%d", obj, value);
}
 
static const char *estado_a_texto(estado_tubo_t e)
{
    switch (e) {
        case TUBO_OK:          return "OK";
        case TUBO_DISPENSANDO: return "DISPENSANDO";
        case TUBO_FALLO:       return "FALLO";
        default:               return "?";
    }
}
 
static void nextion_actualizar_logs(void)
{
    char obj[16];
 
    for (int i = 0; i < MAX_LOGS; i++) {
        snprintf(obj, sizeof(obj), "tLog%d", i + 1);
        if (g_logs[i][0] == '\0') {
            nextion_set_txt(obj, "Sin eventos");
        } else {
            nextion_set_txt(obj, g_logs[i]);
        }
    }
}
 
static void nextion_actualizar_campos_config(void)
{
    for (int i = 0; i < MAX_TUBOS; i++) {
        horario_t hor;
 
        xSemaphoreTake(g_mutex, portMAX_DELAY);
        hor = g_horarios[i];
        xSemaphoreGive(g_mutex);
 
        int h = hor.activo ? hor.hora : 0;
        int m = hor.activo ? hor.minuto : 0;
        int c = hor.activo ? hor.cantidad : 1;
 
        nextion_cmd("nT%dH.val=%d", i + 1, h);
        nextion_cmd("nT%dM.val=%d", i + 1, m);
        nextion_cmd("nT%dC.val=%d", i + 1, c);
    }
}
 
static void nextion_limpiar_campos_config(void)
{
    for (int i = 0; i < MAX_TUBOS; i++) {
        nextion_cmd("nT%dH.val=0", i + 1);
        nextion_cmd("nT%dM.val=0", i + 1);
        nextion_cmd("nT%dC.val=1", i + 1);
    }
}
 
static void nextion_actualizar_horarios_page0(void)
{
    char txt[40];
    char obj[20];
 
    for (int i = 0; i < MAX_TUBOS; i++) {
        horario_t hor;
 
        xSemaphoreTake(g_mutex, portMAX_DELAY);
        hor = g_horarios[i];
        xSemaphoreGive(g_mutex);
 
        if (hor.activo) {
            snprintf(txt, sizeof(txt), "%02d:%02d x%d", hor.hora, hor.minuto, hor.cantidad);
        } else {
            snprintf(txt, sizeof(txt), "Sin horario");
        }
 
        // Nombres esperados en page0: tT1Hor, tT2Hor, tT3Hor, tT4Hor
        snprintf(obj, sizeof(obj), "tT%dHor", i + 1);
        nextion_set_txt(obj, txt);
    }
}
 
static void nextion_actualizar_pantalla(void)
{
    int h = 0, m = 0, s = 0;
    bool rtc_ok = ds3231_get_hora(&h, &m, &s);
 
    char txt[120];
    if (rtc_ok) snprintf(txt, sizeof(txt), "%02d:%02d:%02d", h, m, s);
    else        snprintf(txt, sizeof(txt), "RTC ERROR");
    nextion_set_txt("tHora", txt);
 
    bool alerta_general = false;
    bool fallo_general = false;
 
    for (int i = 0; i < MAX_TUBOS; i++) {
        horario_t hor;
        info_tubo_t info;
 
        xSemaphoreTake(g_mutex, portMAX_DELAY);
        hor = g_horarios[i];
        info = g_info[i];
        xSemaphoreGive(g_mutex);
 
        if (info.alerta_activa) alerta_general = true;
        if (info.estado == TUBO_FALLO) fallo_general = true;
    }
 
    nextion_actualizar_horarios_page0();
 
    if (fallo_general)       nextion_set_txt("tMsg", "Error registrado. Revise mecanismo.");
    else if (alerta_general) nextion_set_txt("tMsg", "Dosis lista. Retirar pastilla.");
    else                    nextion_set_txt("tMsg", "SmartDose listo.");
 
    nextion_set_val("jAlerta", alerta_general ? 100 : 0);
    nextion_actualizar_logs();
}
 
// NVS
 
static void nvs_guardar(void)
{
    char buf[256];
    buf[0] = '\0';
    bool hay = false;
 
    xSemaphoreTake(g_mutex, portMAX_DELAY);
    for (int i = 0; i < MAX_TUBOS; i++) {
        if (!g_horarios[i].activo) continue;
        char tmp[40];
        snprintf(tmp, sizeof(tmp), "%sT%d=%02d:%02d:%d",
                 hay ? ";" : "", i + 1,
                 g_horarios[i].hora, g_horarios[i].minuto, g_horarios[i].cantidad);
        strlcat(buf, tmp, sizeof(buf));
        hay = true;
    }
    xSemaphoreGive(g_mutex);
 
    if (!hay) strlcpy(buf, "VACIO", sizeof(buf));
 
    nvs_handle_t hdl;
    if (nvs_open("smartdose", NVS_READWRITE, &hdl) != ESP_OK) return;
    nvs_set_str(hdl, "horarios", buf);
    nvs_commit(hdl);
    nvs_close(hdl);
    ESP_LOGI(TAG, "Guardado en NVS: %s", buf);
}
 
static void nvs_borrar_horarios(void)
{
    nvs_handle_t hdl;
    if (nvs_open("smartdose", NVS_READWRITE, &hdl) != ESP_OK) return;
 
    // Se deja una marca explicita de estado vacio y tambien se intenta borrar la clave.
    // Esto evita que queden horarios antiguos si hubo un reinicio inesperado.
    nvs_set_str(hdl, "horarios", "VACIO");
    nvs_commit(hdl);
    nvs_close(hdl);
 
    ESP_LOGI(TAG, "Horarios borrados de NVS");
}
 
static void nvs_cargar(void)
{
    nvs_handle_t hdl;
    if (nvs_open("smartdose", NVS_READONLY, &hdl) != ESP_OK) return;
 
    char buf[256];
    size_t len = sizeof(buf);
    esp_err_t err = nvs_get_str(hdl, "horarios", buf, &len);
    nvs_close(hdl);
 
    if (err != ESP_OK || strcmp(buf, "VACIO") == 0) return;
 
    char *sp = NULL;
    char *tok = strtok_r(buf, ";", &sp);
    while (tok) {
        int t = 0, h = 0, m = 0, c = 1;
        if (sscanf(tok, "T%d=%d:%d:%d", &t, &h, &m, &c) == 4 &&
            t >= 1 && t <= MAX_TUBOS && h >= 0 && h <= 23 &&
            m >= 0 && m <= 59 && c >= 1 && c <= 10) {
            g_horarios[t - 1].activo = true;
            g_horarios[t - 1].hora = h;
            g_horarios[t - 1].minuto = m;
            g_horarios[t - 1].cantidad = c;
            ESP_LOGI(TAG, "Cargado: Tubo %d -> %02d:%02d x%d", t, h, m, c);
        }
        tok = strtok_r(NULL, ";", &sp);
    }
}
 
static bool rtc_ya_configurado(void)
{
    nvs_handle_t hdl;
    if (nvs_open("smartdose", NVS_READONLY, &hdl) != ESP_OK) return false;
 
    uint8_t flag = 0;
    esp_err_t err = nvs_get_u8(hdl, "rtc_set", &flag);
    nvs_close(hdl);
    return (err == ESP_OK && flag == 1);
}
 
static void marcar_rtc_configurado(void)
{
    nvs_handle_t hdl;
    if (nvs_open("smartdose", NVS_READWRITE, &hdl) != ESP_OK) return;
 
    nvs_set_u8(hdl, "rtc_set", 1);
    nvs_commit(hdl);
    nvs_close(hdl);
}
 
// LOG
 
static void smartdose_log(int tubo, const char *nivel, const char *codigo, const char *msg)
{
    int h = 0, m = 0, s = 0;
    ds3231_get_hora(&h, &m, &s);
 
    char linea[LOG_LEN];
 
    if (tubo >= 0 && tubo < MAX_TUBOS) {
        if (codigo && codigo[0] != '\0') {
            snprintf(linea, sizeof(linea), "%02d:%02d:%02d | %s %s | T%d | %s",
                     h, m, s, nivel, codigo, tubo + 1, msg);
        } else {
            snprintf(linea, sizeof(linea), "%02d:%02d:%02d | %s | T%d | %s",
                     h, m, s, nivel, tubo + 1, msg);
        }
    } else {
        if (codigo && codigo[0] != '\0') {
            snprintf(linea, sizeof(linea), "%02d:%02d:%02d | %s %s | SYS | %s",
                     h, m, s, nivel, codigo, msg);
        } else {
            snprintf(linea, sizeof(linea), "%02d:%02d:%02d | %s | SYS | %s",
                     h, m, s, nivel, msg);
        }
    }
 
    printf("%s\n", linea);
 
    for (int i = MAX_LOGS - 1; i > 0; i--) {
        strlcpy(g_logs[i], g_logs[i - 1], sizeof(g_logs[i]));
    }
    strlcpy(g_logs[0], linea, sizeof(g_logs[0]));
 
    nextion_actualizar_logs();
 
    char resumen[120];
    if (tubo >= 0 && tubo < MAX_TUBOS) {
        snprintf(resumen, sizeof(resumen), "Tubo %d: %s", tubo + 1, msg);
    } else {
        snprintf(resumen, sizeof(resumen), "%s", msg);
    }
    nextion_set_txt("tMsg", resumen);
}
 
static void log_evento(int tubo, const char *nivel, const char *msg)
{
    smartdose_log(tubo, nivel, "", msg);
}
 
static void log_error_01(int tubo)
{
    smartdose_log(tubo, "ERROR", "01", "Falla de dispensacion: no se detecto dosis; posible atasco, tubo vacio o falla del motor");
}
 
// DISPENSACION
 
static bool hay_alguna_alerta_activa(void)
{
    bool hay = false;
    xSemaphoreTake(g_mutex, portMAX_DELAY);
    for (int i = 0; i < MAX_TUBOS; i++) {
        if (g_info[i].alerta_activa || g_info[i].pastilla_en_bandeja) {
            hay = true;
            break;
        }
    }
    xSemaphoreGive(g_mutex);
    return hay;
}
 
static void actualizar_salidas_alarma(void)
{
    if (hay_alguna_alerta_activa()) {
        led_set(true);
        buzzer_set(true);
    } else {
        led_set(false);
        buzzer_set(false);
    }
}
 
static bool dispensar_con_reintentos_y_confirmar_bandeja(int idx, int cantidad)
{
    if (cantidad < 1) cantidad = 1;
    if (cantidad > 10) cantidad = 10;
 
    for (int intento = 1; intento <= MAX_REINTENTOS_CAIDA; intento++) {
        char msg[120];
        snprintf(msg, sizeof(msg), "Tubo %d intento %d/%d", idx + 1, intento, MAX_REINTENTOS_CAIDA);
        log_evento(idx, "INFO", msg);
        nextion_set_txt("tMsg", msg);
 
        servo_dispensar(idx, cantidad);
 
        int64_t t0 = millis();
        while ((millis() - t0) < TIMEOUT_CAIDA_MS) {
            if (bandeja_tiene_pastilla(idx)) {
                return true;
            }
            vTaskDelay(pdMS_TO_TICKS(100));
        }
 
        char warn_msg[120];
        snprintf(warn_msg, sizeof(warn_msg), "No se detecto pastilla. Reintento %d/%d",
                 intento, MAX_REINTENTOS_CAIDA);
        log_evento(idx, "WARN", warn_msg);
        nextion_set_txt("tMsg", "No cayo dosis. Reintentando...");
    }
 
    return false;
}
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
void app_main(void)
{
    esp_err_t ret = nvs_flash_init();
    if (ret == ESP_ERR_NVS_NO_FREE_PAGES || ret == ESP_ERR_NVS_NEW_VERSION_FOUND) {
        ESP_ERROR_CHECK(nvs_flash_erase());
        ret = nvs_flash_init();
    }
    ESP_ERROR_CHECK(ret);
 
    g_mutex = xSemaphoreCreateMutex();
    if (!g_mutex) {
        ESP_LOGE(TAG, "No se pudo crear mutex");
        return;
    }
 
    for (int i = 0; i < MAX_TUBOS; i++) {
        g_horarios[i].activo = false;
        g_horarios[i].hora = 0;
        g_horarios[i].minuto = 0;
        g_horarios[i].cantidad = 1;
        g_info[i].estado = TUBO_OK;
        g_info[i].pastilla_en_bandeja = false;
        g_info[i].alerta_activa = false;
        g_ultimo_minuto[i] = -1;
    }
 
   
    for (int i = 0; i < MAX_LOGS; i++) {
        strlcpy(g_logs[i], "Sin eventos", sizeof(g_logs[i]));
    }
 
    ledc_timer_config_t timer = {
        .speed_mode      = LEDC_HIGH_SPEED_MODE,
        .timer_num       = LEDC_TIMER_0,
        .duty_resolution = LEDC_TIMER_14_BIT,
        .freq_hz         = SERVO_FREQ_HZ,
        .clk_cfg         = LEDC_AUTO_CLK,
    };
    ESP_ERROR_CHECK(ledc_timer_config(&timer));
 
    for (int i = 0; i < MAX_TUBOS; i++) {
        ledc_channel_config_t ch = {
            .gpio_num   = SERVO_GPIOS[i],
            .speed_mode = LEDC_HIGH_SPEED_MODE,
            .channel    = (ledc_channel_t)(LEDC_CHANNEL_0 + i),
            .timer_sel  = LEDC_TIMER_0,
            .duty       = angulo_a_duty(SERVO_ANGULO_CERRADO),
            .hpoint     = 0,
        };
        ESP_ERROR_CHECK(ledc_channel_config(&ch));
    }
 
    for (int i = 0; i < MAX_TUBOS; i++) {
        gpio_config_t cfg_band = {
            .pin_bit_mask = (1ULL << IR_BAND_GPIOS[i]),
            .mode = GPIO_MODE_INPUT,
            .pull_up_en = GPIO_PULLUP_ENABLE,
            .pull_down_en = GPIO_PULLDOWN_DISABLE,
            .intr_type = GPIO_INTR_DISABLE,
        };
        ESP_ERROR_CHECK(gpio_config(&cfg_band));
    }
 
    gpio_config_t out = {
        .pin_bit_mask = (1ULL << PIN_BUZZER) | (1ULL << PIN_LED),
        .mode = GPIO_MODE_OUTPUT,
        .pull_up_en = GPIO_PULLUP_DISABLE,
        .pull_down_en = GPIO_PULLDOWN_DISABLE,
        .intr_type = GPIO_INTR_DISABLE,
    };
    ESP_ERROR_CHECK(gpio_config(&out));
    gpio_set_level(PIN_BUZZER, 0);
    gpio_set_level(PIN_LED, 0);
 
    i2c_config_t i2c = {
        .mode = I2C_MODE_MASTER,
        .sda_io_num = PIN_SDA,
        .scl_io_num = PIN_SCL,
        .sda_pullup_en = GPIO_PULLUP_ENABLE,
        .scl_pullup_en = GPIO_PULLUP_ENABLE,
        .master.clk_speed = 400000,
    };
    ESP_ERROR_CHECK(i2c_param_config(I2C_PORT, &i2c));
    ESP_ERROR_CHECK(i2c_driver_install(I2C_PORT, I2C_MODE_MASTER, 0, 0, 0));
 
    uart_config_t uart_cfg = {
        .baud_rate  = UART_BAUD_CFG,
        .data_bits  = UART_DATA_8_BITS,
        .parity     = UART_PARITY_DISABLE,
        .stop_bits  = UART_STOP_BITS_1,
        .flow_ctrl  = UART_HW_FLOWCTRL_DISABLE,
        .source_clk  = UART_SCLK_DEFAULT,
    };
    ESP_ERROR_CHECK(uart_param_config(UART_NUM_CFG, &uart_cfg));
    ESP_ERROR_CHECK(uart_driver_install(UART_NUM_CFG, UART_BUF * 2, 0, 0, NULL, 0));
 
    uart_config_t uart_nextion = {
        .baud_rate  = NEXTION_BAUD,
        .data_bits  = UART_DATA_8_BITS,
        .parity     = UART_PARITY_DISABLE,
        .stop_bits  = UART_STOP_BITS_1,
        .flow_ctrl  = UART_HW_FLOWCTRL_DISABLE,
        .source_clk  = UART_SCLK_DEFAULT,
    };
    ESP_ERROR_CHECK(uart_param_config(UART_NUM_NEXTION, &uart_nextion));
    ESP_ERROR_CHECK(uart_set_pin(UART_NUM_NEXTION, NEXTION_TX_GPIO, NEXTION_RX_GPIO,
                                 UART_PIN_NO_CHANGE, UART_PIN_NO_CHANGE));
    ESP_ERROR_CHECK(uart_driver_install(UART_NUM_NEXTION, NEXTION_BUF * 2, NEXTION_BUF * 2, 0, NULL, 0));
 
    nvs_cargar();
 
    if (!rtc_ya_configurado()) {
        ESP_LOGW(TAG, "RTC no configurado. Inicializando a 17:43:00");
        if (ds3231_set_hora(13, 44, 0)) {
            marcar_rtc_configurado();
            ESP_LOGI(TAG, "RTC configurado correctamente");
        } else {
            ESP_LOGE(TAG, "Error configurando RTC");
        }
    }
 
    int h = 0, m = 0, s = 0;
    if (ds3231_get_hora(&h, &m, &s)) {
        ESP_LOGI(TAG, "DS3231 OK - Hora actual: %02d:%02d:%02d", h, m, s);
    } else {
        ESP_LOGE(TAG, "DS3231 no responde");
    }
 
    for (int i = 0; i < MAX_TUBOS; i++) servo_set(i, SERVO_ANGULO_CERRADO);
 
    xTaskCreate(tarea_scheduler,      "scheduler",      4096, NULL, 6, NULL);
    xTaskCreate(tarea_monitor,        "monitor",        4096, NULL, 4, NULL);
    xTaskCreate(tarea_uart_monitor,   "uart_monitor",   4096, NULL, 3, NULL);
    xTaskCreate(tarea_nextion_rx,     "nextion_rx",     4096, NULL, 5, NULL);
    xTaskCreate(tarea_nextion_update, "nextion_update", 4096, NULL, 2, NULL);
 
    ESP_LOGI(TAG, "=== SmartDose listo con Nextion y solo sensor de bandeja ===");
}

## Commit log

2026-03-24 cambios de forma
2026-04-01 Parte de Soto
    Hola chiqui tqm
2026-05-23 organización
    [Matriz de trazabilidad de requerimientos (SRTM) - SmartDose.xlsx]
2026-05-23 Revert "Agrego codigo 1 main SmartDose"
    This reverts commit 8bf7e5550a11409a6fd01f00e726512f532dc3d9.
    [main.c]
2026-05-23 Agrego codigo al main de SmartDose
2026-05-23 Rename Diagrama de bloques.jpg.jpeg to 04_Diagrama_de_bloques
2026-05-24 Create 04_Diagrama_De_Bloques.md
    Diagrama de bloques actualizado
2026-05-24 Delete Docs/04_Diagrama_de_bloques
    Tipo de archivo incorrecto, ya hay otro correcto
2026-05-24 Rename Matriz de trazabilidad de requerimientos (SRTM) - SmartDose.xlsx to 11_Matriz_de_trazabilidad_de_requerimientos_(SRTM).xlsx
    [11_Matriz_de_trazabilidad_de_requerimientos_(SRTM).xlsx]
2026-05-24 cración carpeta
    [10_Gestión_Comunicaciones.xlsx, 11_Matriz_de_trazabilidad_de_requerimientos_(SRTM).xlsx]
2026-05-25 archivos stl
    [Bloqueo.stl, base.stl, rotador.stl]
2026-05-25 Delete Images/DiseñoFísico.png
    Imagen borrada. Próximos a subir imagenes de mejor calidad y ángulos
2026-05-25 Estrategia de logging
    Se describe la estrategia de logging del proyecto smart dose
2026-05-25 Imágenes
    [rotador.stl]
2026-05-25 Add files via upload
    Casos de prueba actualizados
